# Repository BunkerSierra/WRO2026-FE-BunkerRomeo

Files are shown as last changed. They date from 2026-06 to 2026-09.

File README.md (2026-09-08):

# Equipo Bunker Romeo – WRO Future Engineers 2026

   

## Índice
 
1.  [Acerca del Equipo](#acerca-del-equipo)
2.  [Resumen del Proyecto](#resumen-proyecto)
3.  [1. Movilidad y Diseño Mecánico](#movilidad-mecanico)
   - [Piezas de Diseño Mecánico (CAD)](#piezas-cad)
   - [Fotos del Vehículo (Estado Actual)](#fotos-del-vehiculo)
4.  [2. Arquitectura de Potencia y Sensores](#arquitectura-potencia)
5.  [3. Arquitectura de Software y Estrategia de Obstáculos](#arquitectura-software)
   - [3.1 Open Challenge](#open-challenge-sw)
   - [3.2 Obstacle Challenge](#obstacle-challenge-sw)
     - [1. Marco del reto y objetivos de diseño](#marco-del-reto)
     - [2. Arquitectura general: máquina de estados](#maquina-de-estados)
     - [3. Conjunto de sensores y asignación de funciones](#sensores-obstaculos)
     - [4. Control de rumbo recto](#control-rumbo-recto)
     - [5. Seguimiento de pilares](#seguimiento-pilares)
     - [6. Decisión de sorteo](#decision-sorteo)
     - [7. Detección de esquinas](#deteccion-esquinas)
     - [8. Giro de esquina](#giro-esquina)
     - [9. Auto-ajuste por perfil de servo](#auto-ajuste-servo)
     - [10. Ingeniería defensiva](#ingenieria-defensiva)
     - [11. Odometría y separación de contadores](#odometria)
     - [12. Metodología y decisiones revertidas](#metodologia-decisiones-revertidas)
6.  [4. Pensamiento Sistémico y Decisiones de Ingeniería](#bitacora-decisiones)
7.  [5. Reproducibilidad y Estructura del Repositorio](#reproducibilidad)
8.  [Videos de la Competencia](#videos-de-la-competencia)
   - [Open Challenge](#open-challenge)
   - [Obstacle Challenge](#obstacle-challenge)
9.  [BOM (Bill of Materials)](#bom)
---
 
## Acerca del Equipo

Somos **Equipo Bunker Romeo**, de Bunker Robotics, en Baja California, México. Este es nuestro segundo año participando en la categoría Future Engineers, y comenzamos la preparación de esta temporada en enero de 2025. Entre los dos sumamos experiencia en las categorías Robomission Junior, Robomission Senior y Future Engineers.

<div align="center">
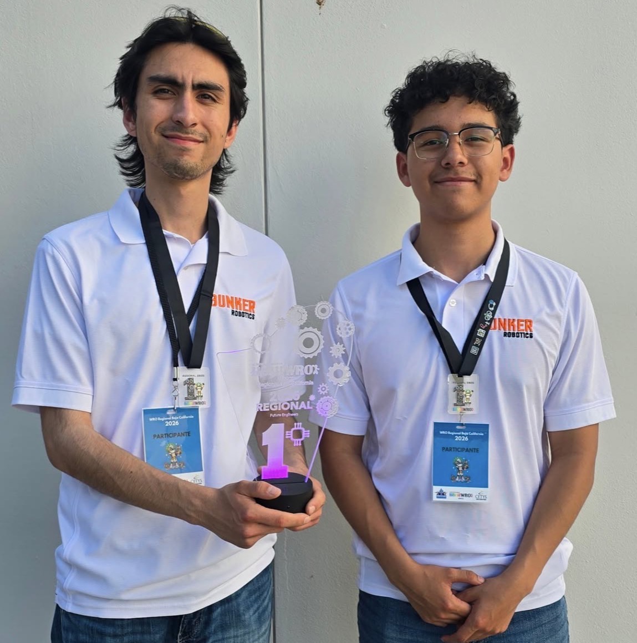
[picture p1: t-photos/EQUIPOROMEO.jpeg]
Equipo Bunker Romeo

</div>

### Jacobo Arteaga Castañeda

**Edad:** 21 años
**Rol:** Operación y desempeño del robot

Compito en WRO desde los 13 años, pasando por las categorías Robomission Junior, Robomission Senior y, desde la temporada 2025, Future Engineers. He tenido la oportunidad de representar a México en la Final Internacional en dos ocasiones: 2021 y 2025. Dentro del equipo soy el responsable de la operación del robot en pista — la puesta a punto antes de cada ronda, el manejo del vehículo durante las corridas de prueba y la lectura del comportamiento real del robot, que es de donde salen la mayoría de los ajustes documentados en la bitácora de este repositorio.

### Ian Fernando Rivera Armenta

**Edad:** 18 años
**Rol:** Documentación y repositorio

Llevo un año en la competencia. Me preparé para Robomission Senior en la temporada 2024 y debuté en Future Engineers, donde en mi primer regional obtuvimos el reconocimiento como mejor equipo. Dentro del equipo soy el responsable del repositorio y de la documentación de ingeniería: mantener el registro de cada decisión de diseño, su justificación y la evidencia que la respalda, además de la organización del código y los archivos técnicos que se publican aquí.

[⬆ Volver al índice](#indicleto)
 
---

## Resumen del Proyecto

Vehículo autónomo desarrollado para la categoría **WRO Future Engineers 2026**, construido sobre un Arduino Mega 2560 con tracción trasera por motor único y dirección por servomotor. El robot resuelve los dos retos con estrategias de navegación distintas: seguimiento de muro por PID en el Open Challenge, y una máquina de estados con visión por color en el Obstacle Challenge.

| | |
|---|---|
| **Dimensiones** | 18.8 × 14.6 × 20.3 cm (largo × ancho × alto) — límite reglamentario: 30 × 20 × 30 cm |
| **Peso** | 817 g — límite reglamentario: 1.5 kg |
| **Tracción** | Motor GA37-520 (300 RPM) con transmisión 1:1 a las ruedas |
| **Percepción** | 2 × VL53L0X (ToF lateral), HC-SR04P (frontal), MPU9250 (rumbo), HuskyLens (color), encoder (odometría) |
| **Mejor tiempo Open Challenge** | **75 s** (3 vueltas + detención en sección de inicio) |
| **Corrida Obstacle Challenge** | **2 min 18 s** completos, autónomos, sin desplazar señales |

**Resultados medidos que respaldan las decisiones de diseño:**

- Reducción del tiempo de Open Challenge de **95 s → 75 s** (≈21 %) al migrar la navegación de rumbo por giroscopio a seguimiento de muro con sensores láser, lo que permitió subir la velocidad del robot sin perder precisión de trayectoria (Decisión 9).
- Corrección de una fuente mecánica de deriva que desviaba la trayectoria recta, eliminando las autocorrecciones constantes del robot en tramo largo (Decisión 13).
- Reducción del footprint del chasis en 2 cm de largo y 2 cm de ancho respecto a la temporada anterior (Decisión 3).
- Altura total reducida de 23.9 cm a **20.3 cm** con el cambio de ruedas (Decisión 3).

[⬆ Volver al índice](#indicleto)
 
---

## 1. Movilidad y Diseño Mecánico

> [!NOTE]
> El razonamiento detrás de cada decisión mecánica —qué alternativas se consideraron y por qué se eligió cada solución— se documenta a detalle en la [Bitácora de Decisiones de Ingeniería](#bitacora-decisiones).

| Aspecto | Especificación actual |
|---|---|
| Ruedas | 57 × 14 mm (Lego Spike Prime) |
| Altura total | 20.3 cm |
| Largo total | 18.8 cm |
| Ancho total | 14.6 cm |
| Peso total | 817 g |
| Controlador principal | Arduino Mega 2560 |

> [!NOTE]
> El chasis fue rediseñado a partir de una versión anterior que usaba ruedas de 62.4 × 20 mm (altura 23.9 cm, ancho 15 cm). Razonamiento completo en la Bitácora, **Decisión 3**.

> [!NOTE]
> Se corrigió un orificio de eje mal dimensionado en el soporte impreso del motor, que causaba una deriva excesiva (~45°) al avanzar en línea recta. La deriva se redujo considerablemente tras el ajuste, aunque persiste en menor grado. Razonamiento completo en la Bitácora, **Decisión 13**.

### Análisis de velocidad y par en rueda

La transmisión entre el motor y las ruedas usa engranes de **1:1** (mismo número de dientes en ambos, por lo que giran a la misma velocidad angular) — es decir, las RPM de la rueda son las mismas que las RPM del motor, sin reducción ni multiplicación.

**Velocidad lineal teórica.** Con el motor **GA37-520** a **300 RPM** (ficha) y ruedas de **57 mm de diámetro**:

```
v = π × D_rueda × RPM / 60
v = π × 0.057 m × 300 / 60
v ≈ 0.895 m/s  (≈ 89.5 cm/s ≈ 3.22 km/h)
```

Esta es la velocidad lineal máxima teórica sin carga; en pista, la velocidad real es menor por la fricción, el peso del robot y el control por PWM.

**Par en la rueda.** El BOM reporta un rango de potencia del motor de **5.55–16.65 W**. A 300 RPM, la velocidad angular es ω = 2π × 300/60 ≈ 31.42 rad/s. Con τ = P/ω:

| | Potencia | Par (τ = P/ω) | Fuerza en el suelo (F = τ / r, r = 28.5 mm) |
|---|---|---|---|
| Mínimo | 5.55 W | ≈ 0.177 N·m (≈ 1.80 kgf·cm) | ≈ 6.2 N (≈ 0.63 kgf) |
| Máximo | 16.65 W | ≈ 0.530 N·m (≈ 5.40 kgf·cm) | ≈ 18.6 N (≈ 1.90 kgf) |

Como la relación de transmisión es 1:1, el par disponible en la rueda es el mismo que el par de salida del motor — no hay ganancia ni pérdida mecánica por relación de engranes, a diferencia de una transmisión reductora.

**Relación con el resultado empírico.** La velocidad teórica de arriba solo se aprovecha si el robot puede correr cerca de ella sin perder el rumbo, y ahí es donde el análisis mecánico se conecta con las decisiones de navegación. Con una transmisión 1:1 no existe una reducción que amortigüe los errores de trayectoria: cada grado de deriva se traduce directamente en distancia recorrida de más y en tiempo perdido autocorrigiendo. Por eso, mientras la navegación dependía del rumbo por giroscopio, la velocidad tenía que mantenerse baja para que el error acumulado no creciera — y el recorrido tomaba **95 segundos**. Al pasar a seguimiento de muro (Bitácora, **Decisión 9**), la referencia dejó de acumular error y pudimos subir la velocidad hasta **75 segundos**. La corrección de deriva mecánica posterior (**Decisión 13**) atacó el mismo problema desde el lado del hardware, permitiendo que esa velocidad se sostuviera en línea recta.

### Piezas de Diseño Mecánico (CAD)

> [!NOTE]
> Todos los archivos `.STL` referenciados aquí están disponibles en la carpeta [`/cad`](cad/) del repositorio. Las dimensiones de cada pieza (caja delimitadora) se obtuvieron directamente del archivo 3D, no son estimaciones.

#### Soporte del sensor láser (VL53L0X)

El soporte impreso en 3D de los sensores láser VL53L0X se rediseñó para elevar al sensor **casi 4 cm por encima** del soporte anterior de MDF. Esta corrección de altura resuelve directamente el hallazgo documentado en la Bitácora (**Decisión 12/13**): el soporte de MDF dejaba al sensor con una leve inclinación hacia el piso, lo que producía falsas lecturas de cercanía (el sensor "veía" el suelo en lugar del muro lateral). Con la nueva geometría, el sensor mide de forma más constante y confiable.

- **Archivo:** [`SoporteLaser.STL`](cad/SoporteLaser.STL)
- **Material:** impreso en 3D (PLA)
- **Dimensiones (caja delimitadora):** 33.9 × 3.1 × 58.6 mm

> [!NOTE]
> Con esta pieza, la falla de montaje que documentamos como "en proceso" en la Bitácora (**Decisión 12**) queda **resuelta** — lo actualizamos en esa entrada.

#### Enlace de dirección y soporte del servomotor

Durante nuestras pruebas encontramos que el barreno de conexión entre el servomotor y el enlace de dirección no estaba centrado: se hallaba desplazado unos milímetros hacia la izquierda. Esto no impedía que el robot funcionara, pero sí desfasaba el ángulo real de las ruedas respecto al ángulo que el servomotor reportaba como centro — es decir, "centro de servo" y "ruedas alineadas" ya no eran el mismo punto. Corregimos la posición del barreno y, aprovechando el rediseño, modificamos también el soporte del servomotor para alojar nuestro nuevo servomotor **ST3215-HS** (ver [Arquitectura de Software](#arquitectura-software) y [Arquitectura de Potencia](#arquitectura-potencia)).
cad/S25_Soporte_Servo_Rev_8.STL
- **Archivo:** [`R26_EnlaceDireccion_Rev7.STL`](cad/R26_EnlaceDireccion_Rev7.STL)[`S25_Soporte_Servo_Rev_8.STL`](cad/S25_Soporte_Servo_Rev_8.STL)
- **Material:** corte en material plano (el enlace en sí no es impreso; el soporte del servomotor que lo acompaña sí es impreso en 3D con PLA)
- **Dimensiones (caja delimitadora):** 116.4 × 3.1 × 17.4 mm

#### Mangueta de dirección

La mangueta es la pieza que se ubica en cada extremo del sistema de dirección y conecta la rueda con el enlace de dirección. Funciona como un pivote: por un lado sostiene el eje/buje de la rueda, y por el otro se articula tanto con el chasis (definiendo el eje de giro de la dirección) como con el enlace de dirección, que es el que recibe el movimiento del servomotor. Cuando el servomotor mueve el enlace de dirección, este empuja o jala la mangueta, haciéndola rotar sobre su propio pivote — y como la rueda está montada directamente en la mangueta, ese giro se traduce en el cambio de ángulo de la rueda. En otras palabras, la mangueta es la que convierte el movimiento lineal/angular del enlace de dirección en el giro real de la rueda.

- **Archivo:** [`S25_Mangueta_Rev_2.STL`](cad/S25_Mangueta_Rev_2.STL)
- **Material:** impreso en 3D (PLA)
- **Dimensiones (caja delimitadora):** 14.4 × 31.9 × 21.0 mm

#### Soporte de motor y transmisión

El eje de salida del motor de tracción está acoplado a ejes Lego, que a su vez conectan directamente con las ruedas. Un soporte personalizado mantiene estos ejes alineados a **180°** entre sí, evitando que se flexionen. Esto es importante por dos razones: evita que se genere una fuerza adicional no deseada sobre el eje Z del motor (que reduciría su vida útil y afectaría la transmisión de potencia), y mantiene un comportamiento consistente y predecible en cada prueba. Esta pieza es de la misma familia que la que corregimos en la Bitácora (**Decisión 13**, orificio de eje mal dimensionado que causaba deriva); esta revisión (**Rev 4B**) es la versión actual, con los ejes correctamente alineados y sin problemas de flexión reportados.

- **Archivo:** [`S25_Soporte_de_motor_y_transmision_Rev_4B.STL`](cad/S25_Soporte_de_motor_y_transmision_Rev_4B.STL)
- **Material:** impreso en 3D (PLA)
- **Dimensiones (caja delimitadora):** 44.5 × 51.8 × 63.5 mm

#### Plataforma / soporte superior

Primer piso del chasis, donde se monta parte de la electrónica del robot.

- **Archivo:** [`R26_piso_1_rev2.STL`](cad/R26_piso_1_rev2.STL)
- **Dimensiones (caja delimitadora):** 114.9 × 3.1 × 26.8 mm

#### Chasis

El chasis se modificó a inicios de esta temporada con el objetivo de reducir el tamaño total del robot y optimizar el acomodo interno de los componentes electrónicos. Como resultado, el chasis actual es **2 cm más corto y 2 cm más angosto** que la versión anterior.

- **Archivo:** [`S25_chasis_rev18.STL`](cad/S25_chasis_rev18.STL)
- **Dimensiones (caja delimitadora):** 177.8 × 3.1 × 135.7 mm

> [!NOTE]
> Material confirmado: la **Mangueta**, el **Soporte de motor y transmisión**, el **Soporte del sensor láser** y el **soporte del servomotor** (parte de la pieza "Enlace de dirección y soporte del servomotor") son impresos en 3D con **PLA**. El **Enlace de dirección** (la barra en sí) es de corte en material plano, no PLA. El **Chasis** y la **Plataforma/Soporte** tienen un espesor uniforme de 3.1 mm en el archivo, consistente con corte en material plano (MDF/acrílico).

### Fotos del Vehículo (Estado Actual)

<table align="center">
<tr>
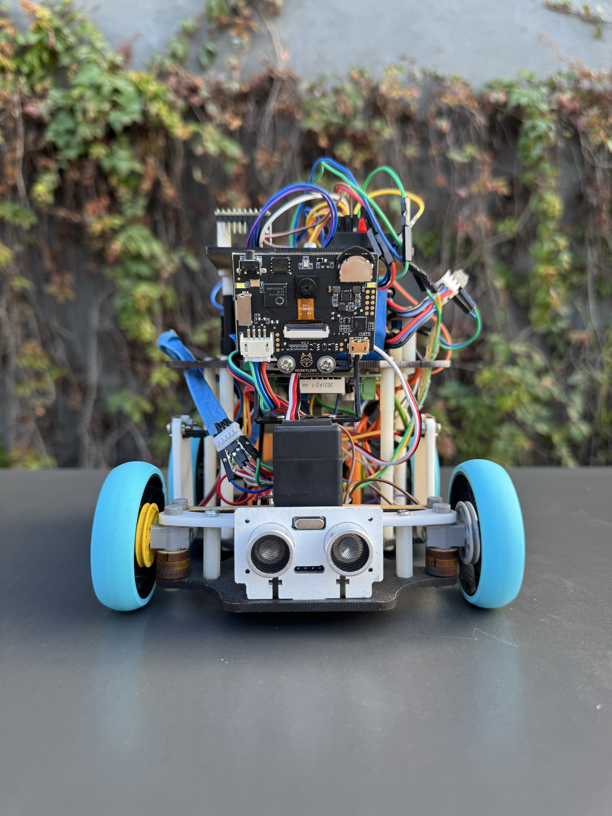
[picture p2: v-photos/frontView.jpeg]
<td align="center"><br><sub>Vista Frontal</sub></td>
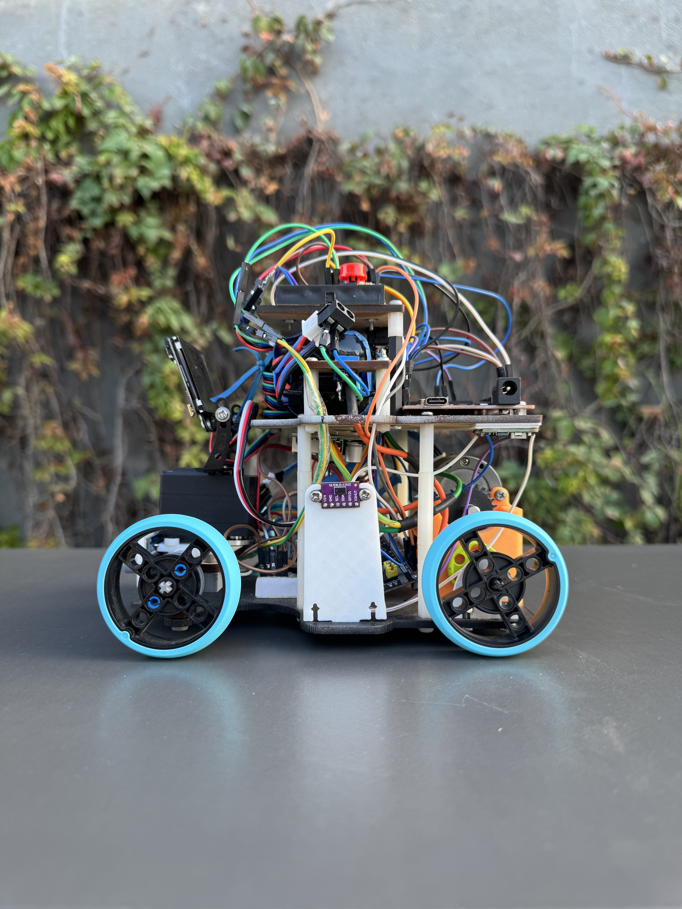
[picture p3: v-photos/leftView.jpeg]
<td align="center"><br><sub>Vista Lateral Izquierda</sub></td>
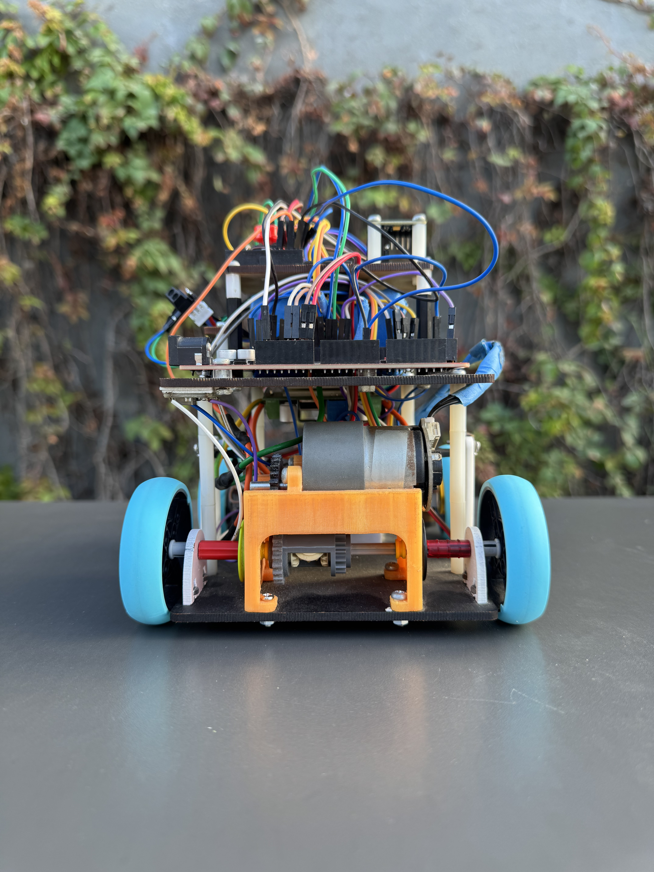
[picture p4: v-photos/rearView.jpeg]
<td align="center"><br><sub>Vista Trasera</sub></td>
</tr>
<tr>
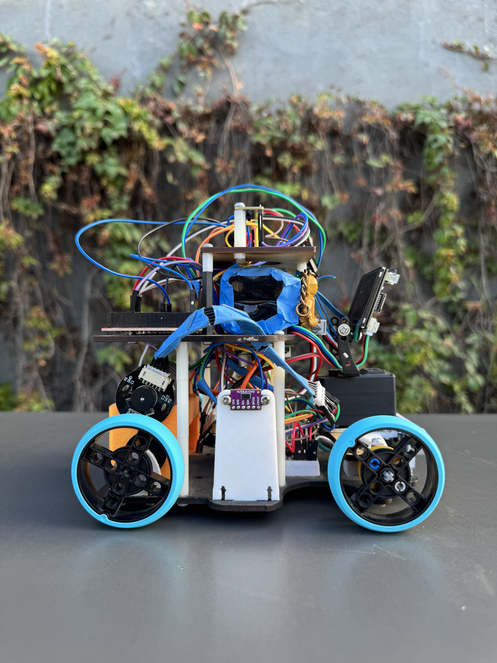
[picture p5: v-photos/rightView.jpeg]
<td align="center"><br><sub>Vista Lateral Derecha</sub></td>
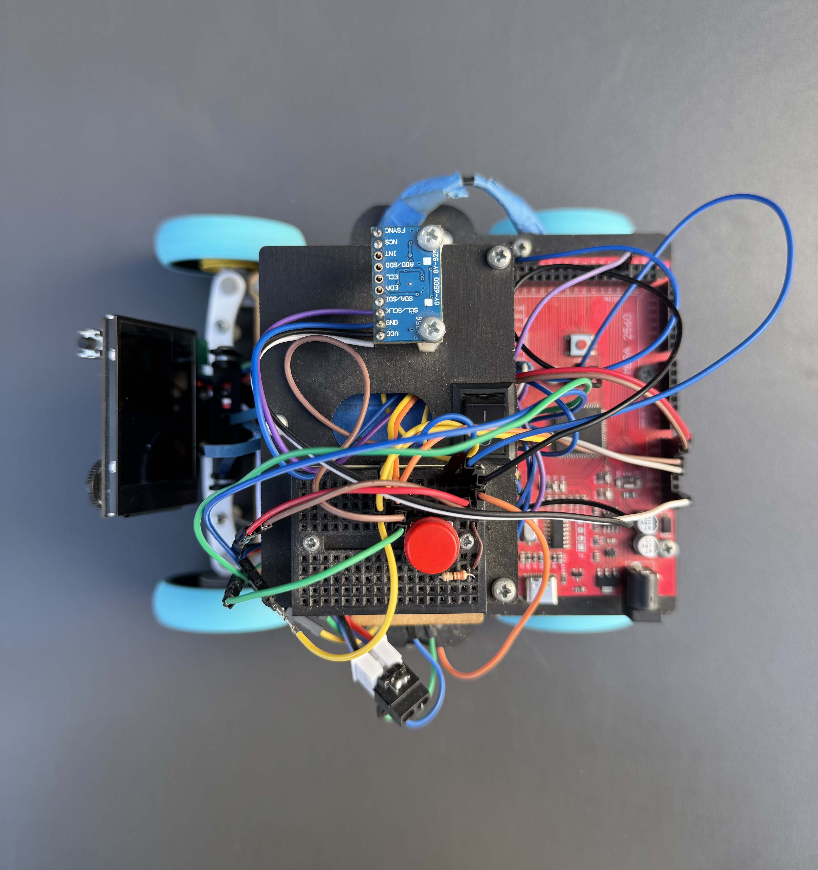
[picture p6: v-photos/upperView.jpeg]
<td align="center"><br><sub>Vista Superior</sub></td>
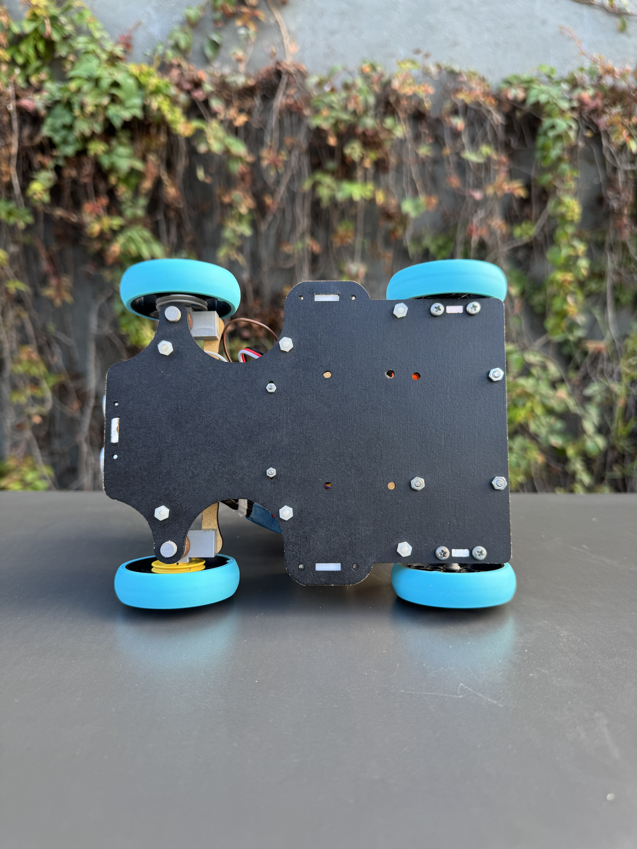
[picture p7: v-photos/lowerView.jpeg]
<td align="center"><br><sub>Vista Inferior</sub></td>
</tr>
</table>

[⬆ Volver al índice](#indicleto)
 
---

## 2. Arquitectura de Potencia y Sensores

> [!NOTE]
> Esta sección detalla cómo se reparte la energía dentro del robot —de la batería a cada sensor y actuador— y el presupuesto de corriente que resulta de esa distribución.

### Topología de alimentación

El robot se alimenta de una sola batería de **15 V**, que pasa primero por un **switch** general y de ahí se reparte entre **dos ramas de regulación step-down**: una hacia control y tracción, y otra dedicada en exclusiva a la dirección.

- **Regulador a 11.1 V:** su salida alimenta directamente al **motor de tracción** (a través del puente H TB6612FNG) y al **Arduino Mega** por su entrada Vin. De los **5 V** que el propio Arduino regula internamente se alimentan los sensores: los **dos sensores láser** (VL53L0X), el **girosensor** (MPU9250/GY-9250), la **cámara** (HuskyLens) y el **sensor ultrasónico** (HC-SR04P).
- **Regulador a 6 V:** alimenta, en línea dedicada, al **servomotor del Open Challenge (MG90S)**.
- **Regulador a 7.5 V:** alimenta, también en línea dedicada, al **servomotor del Obstacle Challenge (Waveshare ST3215-HS)**.

Ambos servos tienen su propia línea de alimentación exclusiva (no comparten regulador con ningún otro componente) porque consideramos que el servomotor es la variable principal de posicionamiento para resolver los retos: si no tiene la corriente disponible en el momento exacto, toda la precisión de dirección se ve comprometida.

<div align="center">
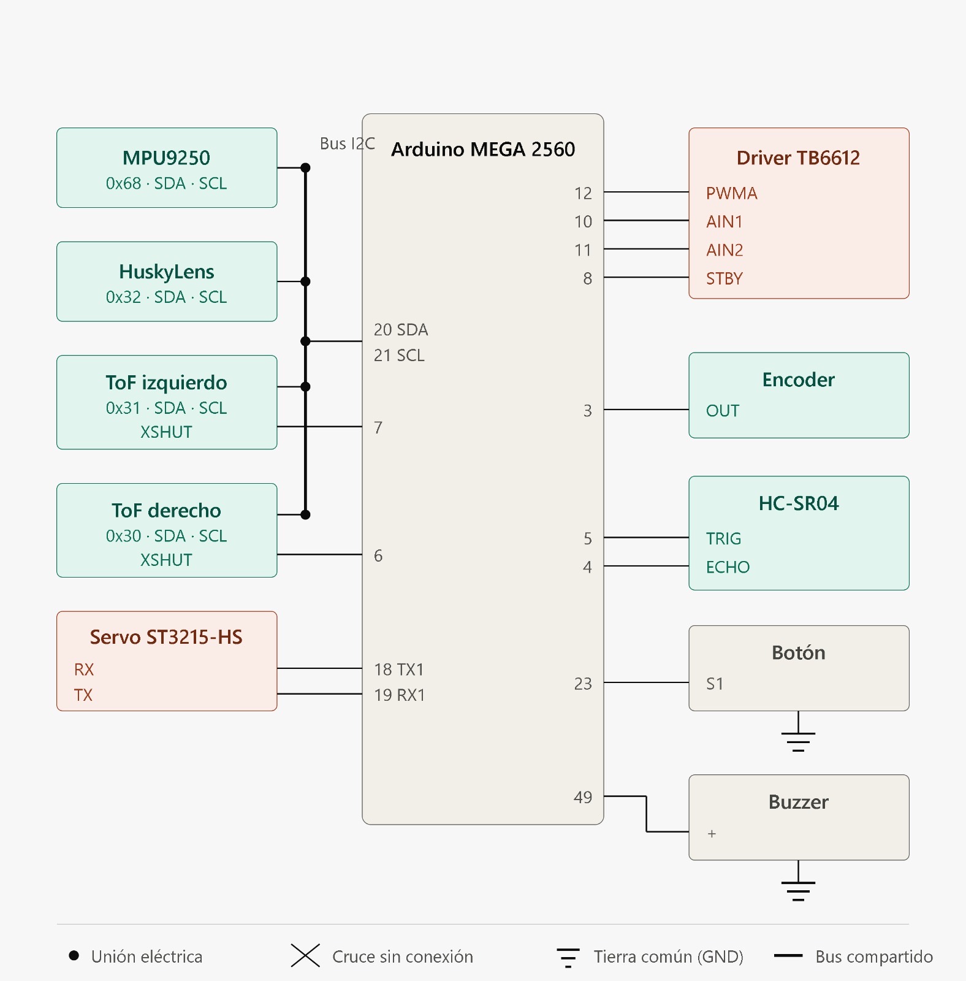
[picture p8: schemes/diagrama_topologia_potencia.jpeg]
Diagrama de topología de alimentación

<br><sub>Topología de alimentación: batería → switch → tres ramas de regulación (11.1 V control/tracción, 6 V servo Open Challenge, 7.5 V servo Obstacle Challenge).</sub>
</div>

```
Batería 15 V → Switch ─┬─ Regulador 11.1 V ─┬─ Motor de tracción (vía TB6612FNG)
                        │                    └─ Arduino Mega → (5 V) → VL53L0X ×2, GY-9250, HuskyLens, HC-SR04P
                        ├─ Regulador 6 V   ──── Servomotor MG90S (Open Challenge, línea dedicada)
                        └─ Regulador 7.5 V ──── Servo ST3215-HS (Obstacle Challenge, línea dedicada)
```

### Diagrama de conexiones (pines)

<div align="center">
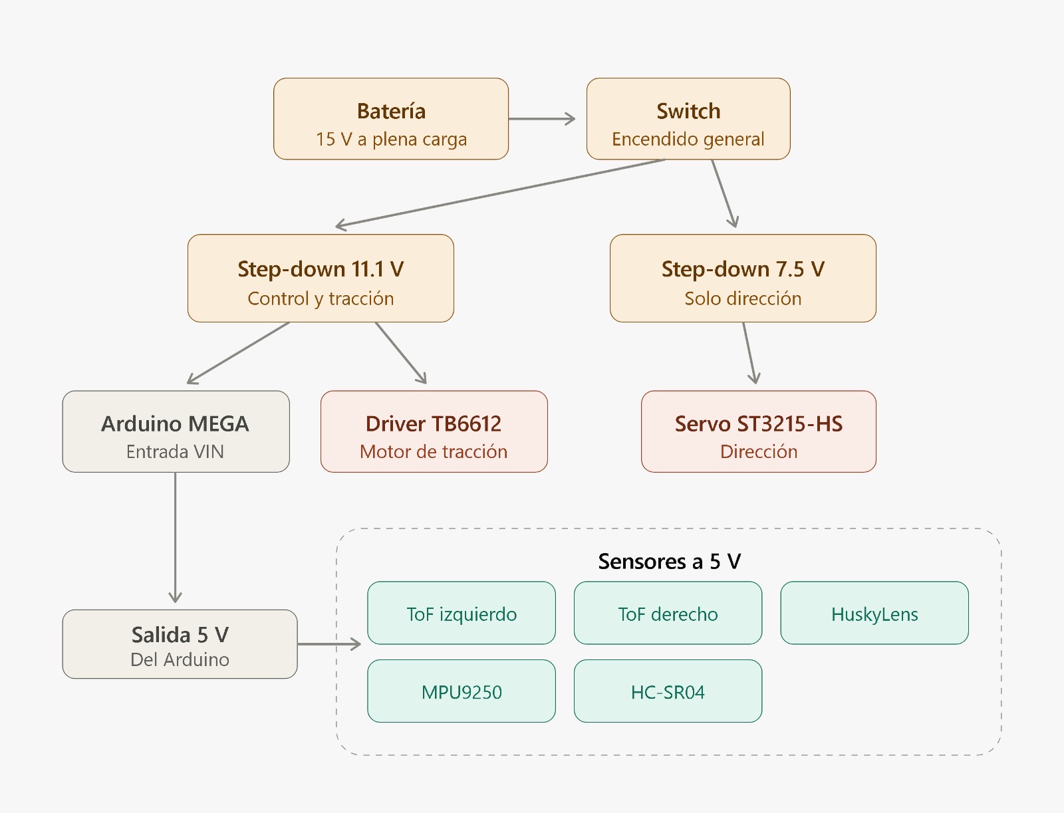
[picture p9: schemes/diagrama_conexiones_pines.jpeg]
Diagrama de conexiones y pines del Arduino Mega

<br><sub>Conexión de cada componente a los pines del Arduino Mega 2560: PWMA/AIN1/AIN2/STBY (12, 10, 11, 8) al driver TB6612; XSHUT (7, 6) y bus I2C (20 SDA, 21 SCL) para los VL53L0X, MPU9250 y HuskyLens; encoder en el pin 3; HC-SR04P en TRIG/ECHO (5, 4); Serial1 (18 TX1, 19 RX1) para el servo ST3215-HS; botón en el pin 23; buzzer en el pin 49.</sub>
</div>

### Presupuesto de corriente

| Componente | Imagen | Voltaje de uso | Consumo de corriente |
|---|---|---|---|
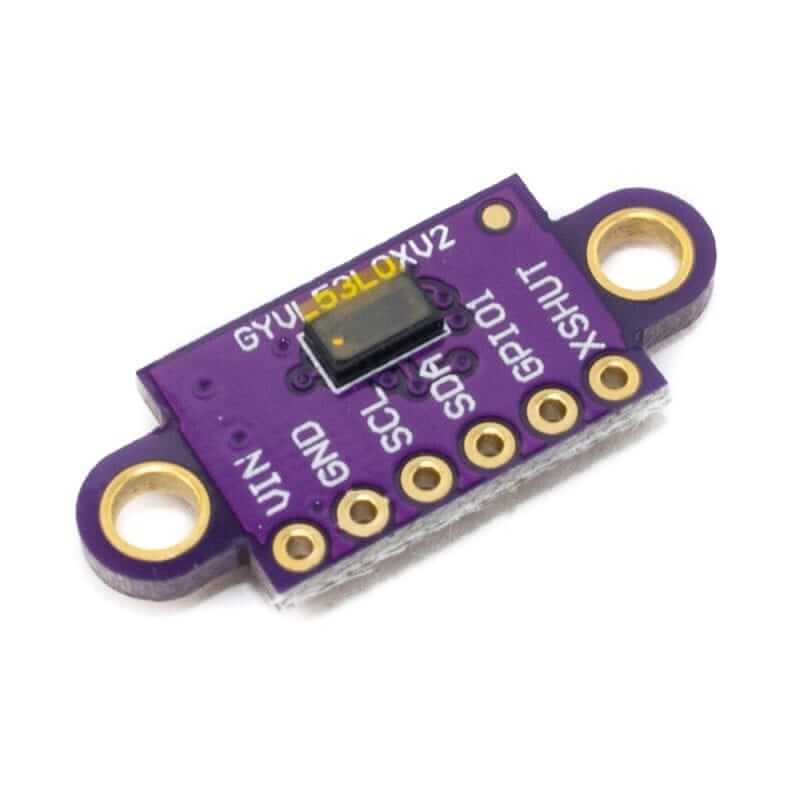
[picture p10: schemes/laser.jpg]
| Sensor láser VL53L0X |  | 5 V | ≈ 10 mA (x2) |
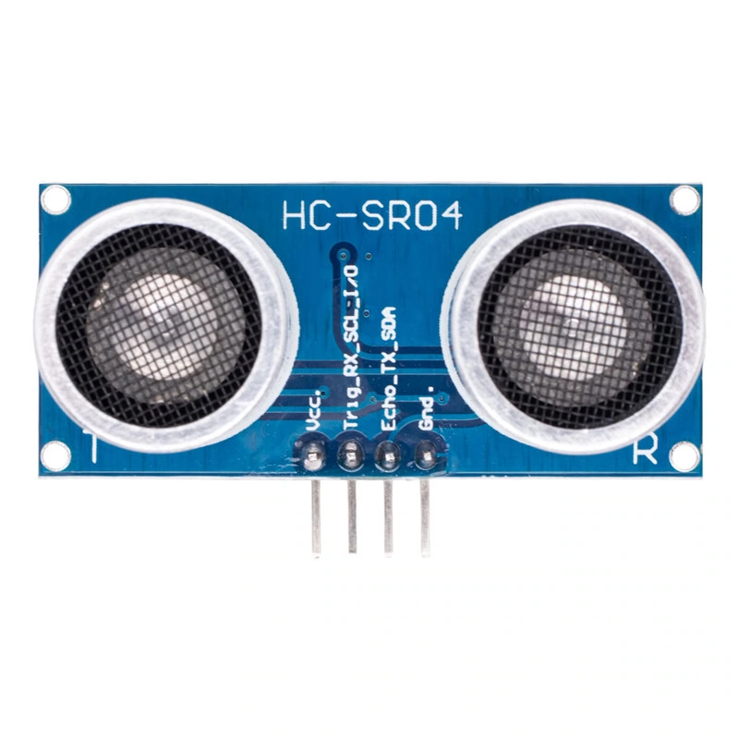
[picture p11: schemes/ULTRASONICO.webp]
| Sensor ultrasónico HC-SR04P |  | 5 V | ≈ 15 mA |
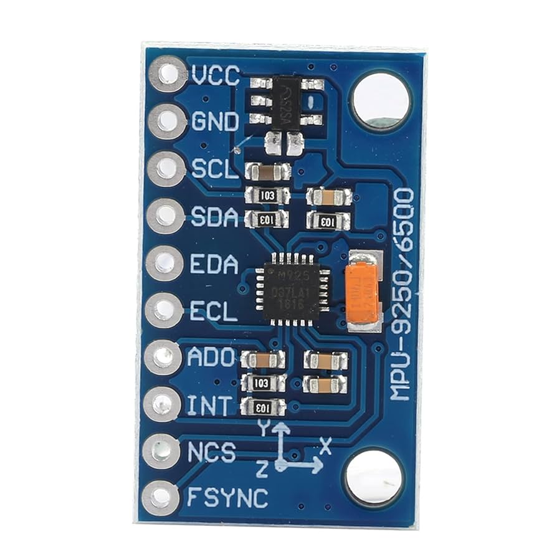
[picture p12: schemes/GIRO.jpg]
| Girosensor GY-9250 |  | 5 V | ≈ 6.6 mA |
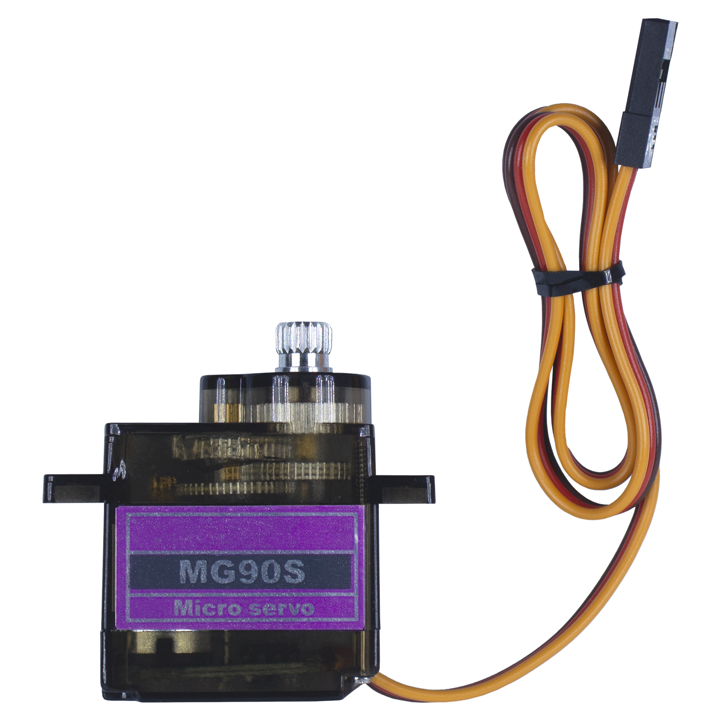
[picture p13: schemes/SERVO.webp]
| Servomotor MG90S (Open Challenge) |  | 6 V | ≈ 83–417 mA |
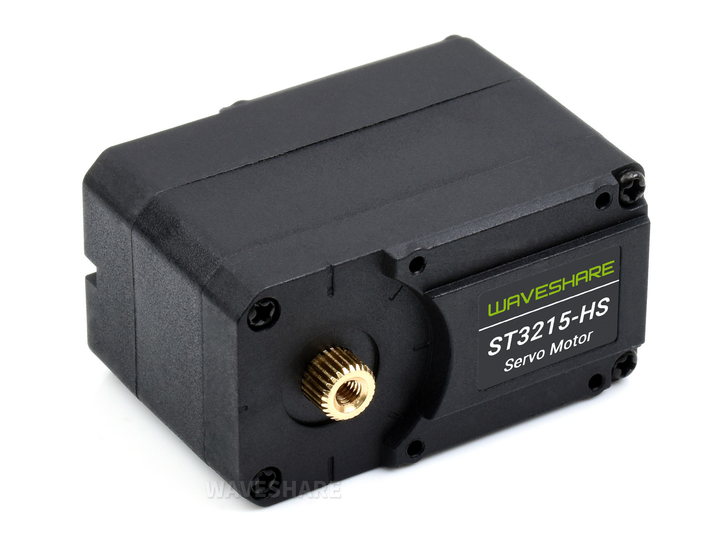
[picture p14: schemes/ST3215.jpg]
| Servo ST3215-HS (Obstacle Challenge) |  | 7.5 V | ≈ 100–900 mA |
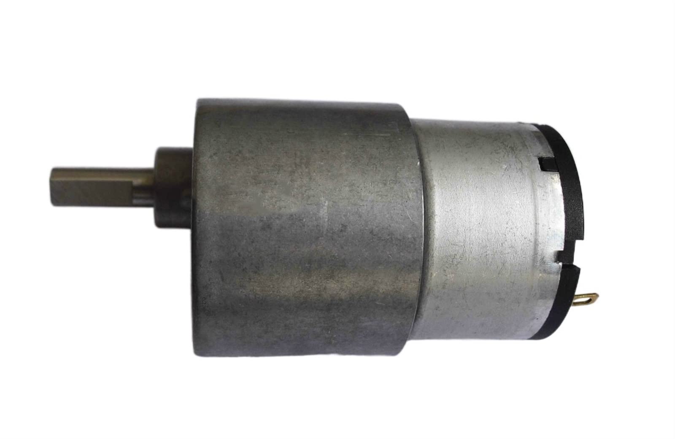
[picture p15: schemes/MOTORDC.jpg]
| Motor de tracción GA37-520 |  | 11.1 V | ≈ 500–1500 mA |
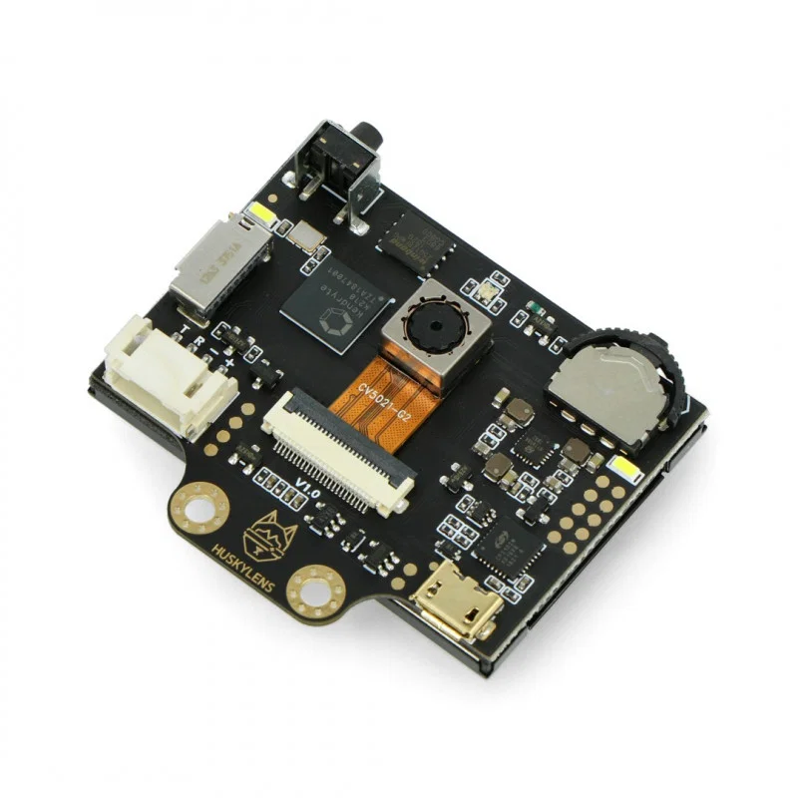
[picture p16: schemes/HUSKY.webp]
| Cámara HuskyLens |  | 5 V | ≈ 320 mA |
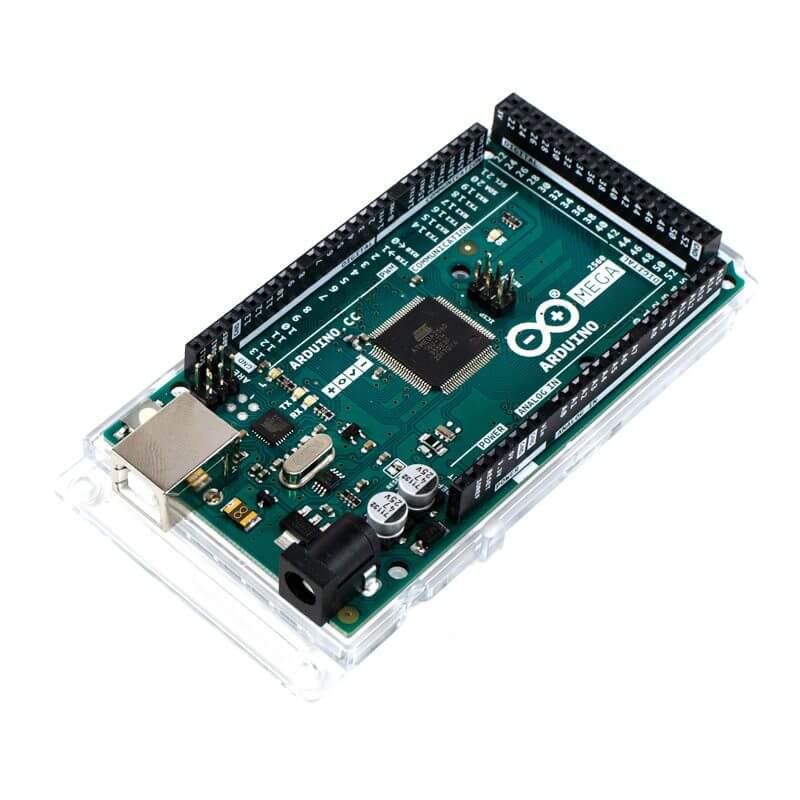
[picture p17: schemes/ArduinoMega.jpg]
| Arduino Mega 2560 |  | 11.1 V | ≈ 22.5–45 mA |
| **Total (Open Challenge)** | | | **≈ 967 mA – 2.32 A** |
| **Total (Obstacle Challenge)** | | | **≈ 984 mA – 2.80 A** |

> [!NOTE]
> Cada consumo se obtuvo de la ficha técnica del componente, referido al voltaje real al que opera en este circuito. Los totales suman corriente de rieles distintos (5 V, 6 V/7.5 V y 11.1 V) según el reto; la corriente que efectivamente entrega la batería es menor y depende de la eficiencia de cada regulador step-down.

[⬆ Volver al índice](#indicleto)
 
---

## 3. Arquitectura de Software y Estrategia de Obstáculos

> [!NOTE]
> Esta sección cuenta, en nuestras propias palabras, **cómo y por qué** funciona el software del robot en cada reto: la arquitectura de control, qué sensor hace qué, el código real que corre en el Arduino, y el razonamiento (y los tropiezos) detrás de cada subsistema. Complementa a la [Bitácora de Decisiones de Ingeniería](#bitacora-decisiones), que lleva la línea de tiempo de los cambios de hardware/algoritmo a nivel de proyecto.

### 3.1 Open Challenge

En el Open Challenge no hay pilares que sortear, así que el problema se reduce a completar 3 vueltas (12 esquinas en total) manteniendo una distancia constante a un muro y girando con precisión en cada esquina. Por eso este programa es más simple que el del Obstacle Challenge: no usa cámara de color, y el servo de dirección es un **MG90S** estándar controlado con la librería `Servo` de Arduino (a diferencia del servo de bus serial que usamos en el Obstacle Challenge).

**Hardware que usa este programa:** servomotor MG90S (dirección), sensor ultrasónico HC-SR04P (frontal), dos VL53L0X laterales (seguimiento de muro), giroscopio MPU6050 vía librería `MPU6050_light` (rumbo y giros), encoder (tramo final), y el puente H TB6612FNG (motor de tracción).

**Detección de esquina y sentido de giro.** El robot avanza hasta que el ultrasónico frontal detecta una pared a **30 cm o menos** (`TD = 30`). En la primerísima esquina de toda la ronda, y solo ahí, compara las dos lecturas laterales VL53L0X (`decideSentido()`): el lado que ve más lejos es el interior de la pista, y ese es el sentido de giro que se usa durante **las 12 esquinas** de la ronda, sin volver a recalcularlo.

**Tramo recto.** Antes de la primera esquina el robot todavía no tiene un muro "conocido" que seguir, así que avanza en línea recta usando el giroscopio (`conduceRectoGiro()`: un control proporcional que corrige el volante para mantener el rumbo en 0°). De la segunda esquina en adelante, cada tramo recto se recorre con **seguimiento de muro por PID** (`Kp=17, Ki=0.5, Kd=35`, punto de ajuste de **15 cm**, función `Wallfolowing()`), siempre sobre el lado **exterior** de la pista — el sensor contrario al lado de giro — porque el muro exterior es continuo, mientras que el interior tiene aberturas en cada esquina.

> [!NOTE]
> **Método de calibración de las ganancias PID:** las tres ganancias se ajustaron de forma empírica y en este orden: primero **Kp**, subiéndola hasta que el robot oscilara visiblemente contra el muro y luego bajándola un escalón; después **Kd**, para amortiguar esa oscilación sin perder capacidad de reacción; y por último **Ki**, en un valor bajo, solo para corregir el desvío sostenido que quedaba en tramos largos. El punto de ajuste de 15 cm se eligió porque deja margen suficiente tanto en el corredor angosto (600 mm) como en el ancho (1000 mm) que define el reglamento para el Open Challenge, sin acercar demasiado al robot al muro interior en el corredor angosto.

**Maniobra de giro.** Al detectar la pared frontal, el robot cierra el giro en lazo con el giroscopio hasta alcanzar un ángulo objetivo (`Giros()`). Estos ángulos se calibraron de forma empírica y son acumulativos dentro de cada vuelta (se reinician cada 4 esquinas): **60°** en la 1ª esquina de la vuelta, **120°** en la 2ª, **182°** en la 3ª y **241°** en la 4ª. Al terminar, el robot reduce su velocidad y continua siguiendo la pared hasta contar cierta cantidad de pulsos con el encoder, y el robot se detiene.

**Cierre de la ronda.** Tras completar las 12 esquinas, el robot reduce la velocidad y continúa con seguimiento de muro por una distancia fija adicional (2555 pulsos de encoder) antes de detenerse — este tramo final lo acerca a la zona de estacionamiento.

<details>
<summary>📄 Ver código completo — Open Challenge (<code>abierto.ino</code>)</summary>

```cpp
#include <Adafruit_VL53L0X.h>  // ToF sensor Library
#include <Servo.h>             // Servomotor Library
#include <Wire.h>              // I2C Library
#include <MPU6050_light.h>     // MPU Library
MPU6050 mpu(Wire);

// Variables para el yaw
float yaw = 0.0;
unsigned long lastTime = 0;
float gyroZOffset = 0.0;

// Para calibración
bool calibrated = false;
const int CALIBRATION_SAMPLES = 510;

volatile int Contador = 0;

unsigned long Cont = 0;
bool izq = false;

float global = 0;

//PID Wall Follower variables
float P, I, D, error, L_error, Servo_OUT, DeltaError, SumError, PID;
float setpoint = 15;  //Centimetros
float Kp = 17, Ki = 0.5, Kd = 35;
float Ts = 0.5;  // Tiempo de sampleo para la suma de la integral

//Trasnmision Motor
const int STBY = 8;
const int PWMA = 12;
const int AIN1 = 10;
const int AIN2 = 11;

//Servo Direccion
Servo SvD;

//Ultrasonic Frontal Sensor
const int triggerPin3 = 5;
const int echoPin3 = 4;
volatile float distanceF;

//ToF Lateral Sensors
#define XSHUT1 6
#define XSHUT2 7
Adafruit_VL53L0X sensor1 = Adafruit_VL53L0X();
Adafruit_VL53L0X sensor2 = Adafruit_VL53L0X();
float medidaD, medidaI;

//Algorithim Variables/Values
float TD = 30;  //Target frontal distance ... CM
bool Turn = true;
bool Orientation = false;
bool Giro = false;
int CV;

int sentidoGiro = 2;     // se decide solo en el 1er corner: 1=derecha, 2=izquierda
float Kp_rumbo = 3.0;    // ganancia del rumbo recto por giroscopio (1er tramo)

void setup() {
  Serial.begin(115200);
  Wire.begin();

  pinMode(3, INPUT_PULLUP);
  attachInterrupt(digitalPinToInterrupt(3), inter, RISING);

  pinMode(triggerPin3, OUTPUT);
  pinMode(echoPin3, INPUT);

  Wire.beginTransmission(0x68);
  Wire.write(0x6B);
  Wire.write(0);
  Wire.endTransmission(true);

  pinMode(STBY, OUTPUT);
  pinMode(PWMA, OUTPUT);
  pinMode(AIN1, OUTPUT);
  pinMode(AIN2, OUTPUT);
  // The motor begins off
  digitalWrite(STBY, LOW);

  pinMode(XSHUT1, OUTPUT);
  pinMode(XSHUT2, OUTPUT);

  SvD.attach(A1);
  delay(50);
  tone(49, 293, 125);
  delay(50);

  SvD.write(105);
  delay(400);

  byte status = mpu.begin();
  while (status != 0) {}

  mpu.calcOffsets();  // Calibración interna de la librería
  calibrateGyroZ();   // Calibración adicional específica para Z

  lastTime = millis();
  calibrated = true;

  tone(49, 1000, 125);

  // Apagar los tres sensores
  digitalWrite(XSHUT1, LOW);
  digitalWrite(XSHUT2, LOW);
  delay(10);

  // Encender sensor 1 y darle dirección 0x30
  digitalWrite(XSHUT1, HIGH);
  delay(10);
  sensor1.begin(0x30);

  // Encender sensor 2 y darle dirección 0x31
  digitalWrite(XSHUT2, HIGH);
  delay(10);
  sensor2.begin(0x31);
  
}

void loop() {

  while (CV < 12) {
    distanceF = TD + 3;
    SUSF();
    delay(20);

    if (distanceF <= TD) {
      if (CV == 0) decideSentido();     // 1er corner: decide el sentido de TODAS las vueltas
      Giros(sentidoGiro, 175, 60);
      tone(49, 290, 75);
      distanceF = TD + 100;
      CV++;
      delay(1);
      if (CV == 4 || CV == 8 || CV == 12) {
        global = 0;
        yaw = 0;
      }
      SvD.write(105);
    } else {
      if (CV == 0) {
        conduceRectoGiro();             // antes del 1er corner: avanza recto por giroscopio (sin seguir pared)
        moverMotor(200);
      } else {
        Wallfolowing();
        moverMotor(200);
      }
    }
  }
  if (CV >= 12) {
    moverMotor(120);
    while (Contador < (Cont + 2555)) {
      Wallfolowing();;
    }
    detenerMotores(1000000000000000000000000000000000000000000000000000);
  }
}

// ===== Decide el sentido de giro en el 1er corner: lee ambos ToF, gira al lado mas abierto =====
void decideSentido() {
  VL53L0X_RangingMeasurementData_t m1, m2;
  sensor1.rangingTest(&m1, false);
  sensor2.rangingTest(&m2, false);
  float izq = m1.RangeMilliMeter / 10.0;   // sensor1 = lado IZQUIERDO (medidaI)
  float der = m2.RangeMilliMeter / 10.0;   // sensor2 = lado DERECHO  (medidaD)
  Serial.print("izq="); Serial.print(izq);
  Serial.print("  der="); Serial.println(der);
  // El lado que mide MAS es el mas abierto -> se gira hacia ese lado.
  // Si decide al reves en tu robot, invierte esta comparacion (cambia > por <).
  if (izq > der) {
    Orientation = false; sentidoGiro = 2;              // abierto IZQUIERDA -> gira izquierda
    tone(49, 1200, 120); delay(160); tone(49, 1200, 120);
  } else {
    Orientation = true;  sentidoGiro = 1;              // abierto DERECHA -> gira derecha
    tone(49, 700, 250);
  }
  delay(150);
}

// ===== Avance recto por giroscopio (rumbo objetivo = 0), sin seguir pared =====
void conduceRectoGiro() {
  GradoZ();                                // actualiza yaw
  float err = 0 - yaw;                      // mantiene el rumbo inicial (yaw = 0)
  int salida = 105 + (int)(Kp_rumbo * err);
  salida = constrain(salida, 35, 160);
  SvD.write(salida);
}

void SUSF() {
  digitalWrite(triggerPin3, LOW);
  delayMicroseconds(2);
  digitalWrite(triggerPin3, HIGH);
  delayMicroseconds(10);
  digitalWrite(triggerPin3, LOW);
  long durationF = pulseIn(echoPin3, HIGH);
  distanceF = durationF / 58;
}
void Wallfolowing() {
  //Obtencion del dato del sensor.
  if (Orientation == true) {
    VL53L0X_RangingMeasurementData_t medida1;
    sensor1.rangingTest(&medida1, false);
    delay(5);
    medidaI = medida1.RangeMilliMeter / 10;
    error = medidaI - setpoint;
  } else {
    VL53L0X_RangingMeasurementData_t medida2;
    sensor2.rangingTest(&medida2, false);
    delay(5);
    medidaD = medida2.RangeMilliMeter / 10;
    error = medidaD - setpoint;
  }
  DeltaError = error - L_error;
  SumError += L_error;
  P = Kp * error;
  I = Ki * Ts * SumError;
  I = constrain(I, -55, 55);
  D = ((Kd / Ts) * DeltaError);
  PID = P + I + D;
  L_error = error;

  PID = constrain(PID, -10, 10);
  if (Orientation == true) {
    Servo_OUT = 105 - PID;
  } else {
    Servo_OUT = 105 + PID;
  }
  SvD.write(Servo_OUT);
}
void moverMotor(int velocidad) {
  digitalWrite(STBY, HIGH);
  if (velocidad > 0) {
    digitalWrite(AIN1, HIGH);
    digitalWrite(AIN2, LOW);
  } else {
    digitalWrite(AIN1, LOW);
    digitalWrite(AIN2, HIGH);
    velocidad = -velocidad;
  }
  analogWrite(PWMA, constrain(velocidad, 0, 255));
}

void inter() {
  Contador++;
}

void MotorEnc(int velocidad, int pulsos) {
  Contador = 0;
  delay(5);

  digitalWrite(STBY, HIGH);
  if (velocidad > 0) {
    digitalWrite(AIN1, HIGH);
    digitalWrite(AIN2, LOW);
    analogWrite(PWMA, constrain(velocidad, 0, 255));
    while (Contador <= pulsos) {}

  } else {
    digitalWrite(AIN1, LOW);
    digitalWrite(AIN2, HIGH);
    analogWrite(PWMA, constrain(-velocidad, 0, 255));
    while (Contador <= pulsos) {}
  }

  detenerMotores(0);
}

void detenerMotores(int T) {
  analogWrite(PWMA, 0);
  digitalWrite(STBY, LOW);  // Standby to save energy
  delay(T);
}

void calibrateGyroZ() {
  float sum = 0;
  for (int i = 0; i < CALIBRATION_SAMPLES; i++) {
    mpu.update();
    sum += mpu.getGyroZ();
    delay(5);
  }
  gyroZOffset = sum / CALIBRATION_SAMPLES;
  Serial.print("Gyro Z Offset: ");
  Serial.println(gyroZOffset, 6);
}

void GradoZ() {
  mpu.update();

  if (calibrated) {
    unsigned long currentTime = millis();
    float deltaTime = (currentTime - lastTime) / 1000.0;  // Tiempo en segundos
    lastTime = currentTime;

    if (deltaTime > 0.1) deltaTime = 0.01;  // Limitar deltaTime máximo

    // Obtener velocidad angular Z (grados/segundo) y aplicar offset
    float gyroZRate = mpu.getGyroZ() - gyroZOffset;

    // INTEGRAR para obtener el ángulo: ángulo = velocidad angular × tiempo
    yaw += gyroZRate * deltaTime;

    // Mantener el yaw en el rango 0-360 grados
    if (yaw <= -360) yaw = 0;
    if (yaw >= 360) yaw = 0;
    Serial.println(yaw);
  }

  delay(12);  // Little Pause for estability
}

void Giros(int d, int V, float G) {
  tone(49, 3520, 50);
  GradoZ();
  float targetYaw;
  if (d == 1) SvD.write(160);
  else { SvD.write(35); }

  delay(50);

  if (CV == 0 || CV == 4 || CV == 8) targetYaw = G;
  else if (CV == 1 || CV == 5 || CV == 9) targetYaw = G * 2;
  else if (CV == 2 || CV == 6 || CV == 10) targetYaw = (G * 3) + 2;
  else if (CV == 3 || CV == 7 || CV == 11) targetYaw = (G * 4) + 1;
  if (d != 1) targetYaw = targetYaw * -1;

  global = targetYaw;

  moverMotor(V);

  while (true) {
    GradoZ();

    if (d == 1) {
      if (yaw >= targetYaw) {
        break;
      }
    } else {
      if (yaw <= targetYaw) {
        break;
      }
    }
  }

  MotorEnc(-115, 13);
  delay(100);

  if (d == 1) dir(160, 105, 10);
  else { dir(35, 105, 10); }

  SvD.write(105);
  delay(50);
  SvD.write(105);
}

void dir(int Vi, int Vf, int T) {
  if (Vi < Vf) {
    for (int pos = Vf; pos <= Vi; pos += 5) {
      SvD.write(pos);
      delay(T);
    }
  } else {
    for (int pos = Vf; pos >= Vi; pos -= 5) {
      SvD.write(pos);
      delay(T);
    }
  }
  SvD.write(105);
}
```

</details>

[⬆ Volver al índice](#indicleto)

---

### 3.2 Obstacle Challenge

#### 1. Marco del reto y objetivos de diseño

El Obstacle Challenge de WRO Future Engineers 2026 le pide al vehículo recorrer, de forma completamente autónoma, tres vueltas a una pista de ocho secciones —cuatro esquinas y cuatro rectas— mientras esquiva señales de tráfico colocadas al azar antes de cada ronda. La regla es simple de decir pero exigente de cumplir: un pilar **rojo** obliga a pasar por su lado **derecho**, uno **verde** por el **izquierdo**, y en ningún caso se puede mover la señal. Como el sentido de la ronda (horario o antihorario) se decide al azar justo antes de arrancar, el algoritmo no puede asumir nada de entrada: tiene que averiguarlo por sí mismo apenas empieza a moverse. Y al final, después de las tres vueltas, hay que volver al estacionamiento.

Desde el principio nos propusimos tres cosas al diseñar el sistema: que aguantara bien la aleatoriedad (posición de pilares, sentido de la ronda), que dependiera lo menos posible de la iluminación o de medidas exactas de la pista, y que se pudiera depurar por partes. Esta última terminó siendo casi la regla de oro del equipo: **medir antes de prescribir**. Cada valor que importaba lo dejamos como una constante ajustable, y cada subsistema lo probamos aislado en su propio programa antes de juntarlo con los demás — así, cuando algo fallaba, sabíamos exactamente en qué módulo buscar.

#### 2. Arquitectura general: máquina de estados

El control del robot está organizado como una **máquina de estados** que, básicamente, calca la forma de la pista. En cada tramo recto, el vehículo pasa por cuatro estados:

- **RECTO:** avanza manteniendo el rumbo.
- **SEGUIR:** al detectar un pilar, lo centra en el cuadro de la cámara mientras se acerca.
- **ESQUIVAR:** al llegar a cierta distancia, ejecuta la maniobra de esquive.
- **REGRESAR:** retoma el rumbo recto.

Por encima de todo esto, el robot también puede entrar en la maniobra de esquina — pero solo si está en estado RECTO. Esa restricción fue una decisión a propósito: así nos aseguramos de que el robot nunca intente doblar una esquina a la mitad de un esquive, resolviendo de una vez el conflicto entre "sortear el pilar" y "tomar la esquina" a favor de lo primero.

Separar el control de esta manera nos permitió que cada tarea usara el sensor que mejor le quedaba, sin que se estorbaran entre sí: la cámara maneja SEGUIR y ESQUIVAR, el giroscopio se encarga del rumbo en RECTO y REGRESAR (y del giro de esquina), los sensores de distancia detectan las esquinas, y el encoder le da la odometría a todas las maniobras.

#### 3. Conjunto de sensores y asignación de funciones

Sobre un Arduino Mega, el robot integra cinco sistemas de percepción/actuación, la mayoría conectados por el mismo bus I2C:

- **Cámara HuskyLens** (modo de reconocimiento de color): detecta los pilares y da su posición horizontal en el cuadro, además de su alto aparente en píxeles, que usamos como estimador de qué tan cerca está el pilar (no usamos un sensor de distancia dedicado para los pilares).
- **Dos sensores de tiempo de vuelo VL53L0X**, en **modo de largo alcance**: detectan cuándo se abre una esquina y, si hace falta, sirven para decidir si conviene un giro hacia adelante o en reversa. La altura de montaje no es arbitraria: el soporte rediseñado (ver [Piezas de Diseño Mecánico](#piezas-cad)) eleva al sensor casi 4 cm respecto al soporte anterior, lo que lo deja apuntando dentro de la franja de los **100 mm de altura** que especifica el reglamento para los muros de la pista (regla 13.3/13.5) — ni tan bajo que lea el piso, ni tan alto que pase por encima del muro.
- **Giroscopio (GY-9250, vía MPU6050):** calcula el rumbo (*yaw*) integrando la velocidad angular — es la base tanto del control en línea recta como de los giros.
- **Encoder** de un canal en el eje de tracción: da la distancia recorrida para todas las maniobras basadas en odometría.
- **Servomotor de dirección Waveshare ST3215:** a diferencia del Open Challenge (que usa un MG90S estándar), aquí usamos un servo de **bus serial** (protocolo half-duplex por `Serial1`, librería `SCServo`), que permite fijar posición, velocidad y aceleración de forma independiente. Esto nos deja calcular cuánto tarda el volante en llegar a cada ángulo y **compensar ese retraso** al calcular las distancias de esquive, giro y frenado (ver punto 9, más abajo) — algo que un servo PWM normal no nos permitiría hacer con la misma precisión.

Repartir las tareas entre sensores especializados, en vez de cargarle todo a la cámara, fue algo que aprendimos por las malas: la cámara ya tenía suficiente trabajo detectando pilares bajo luz variable, y si además le pedíamos distinguir las líneas del piso, se volvía poco confiable. Separar la percepción por dominio —color a la cámara, distancia lateral a los ToF, rumbo al giroscopio— hizo que todo el sistema fuera más robusto.

#### 4. Control de rumbo recto

Al principio pensamos que bastaba con "dejar el volante centrado" para que el robot avanzara recto. No es así: un volante centrado mecánicamente no garantiza una trayectoria recta, y cualquier desalineación —por mínima que sea— se va acumulando como deriva (de hecho, encontramos una causa mecánica concreta de esto; ver Bitácora, **Decisión 13**). Por eso cerramos el rumbo en lazo con el giroscopio: un controlador proporcional corrige el servo según el error entre el rumbo que queremos (`targetYaw`) y el que el giroscopio está midiendo. El movimiento del servo hacia esa corrección se hace de forma gradual (`servoSuave()`, con una velocidad de cambio limitada — `SERVO_SLEW`), para evitar bandazos bruscos en la dirección.

#### 5. Seguimiento de pilares (estado SEGUIR)

Cuando un pilar aparece con un tamaño mínimo en el cuadro (filtro `TAM_MIN`, para no perseguir manchas chiquitas o líneas del piso), el robot entra en SEGUIR y lo mantiene centrado con un controlador **proporcional-derivativo** que ajusta el servo según qué tan lejos está el pilar del centro real de la cámara (`CENTRO_IMG`, ya calibrado). El robot pasa de SEGUIR a la maniobra de esquive cuando el **alto del pilar en píxeles** supera un umbral (`H_ESQUIVAR`) — es decir, la señal de "ya está lo bastante cerca" viene del tamaño aparente en la cámara, no de un sensor de distancia dedicado.

- **Un error de signo bastante instructivo:** en una primera versión, el robot se **alejaba** del pilar en vez de seguirlo. Visto desde afuera parecía que estaba esquivando la caja, y al perderla de vista se enderezaba solo — se veía exactamente como un esquive, pero en realidad era el seguidor corrigiendo al revés. Bastó con invertir el signo del lazo de la cámara para que empezara a converger correctamente hacia el centro.
- Si el robot pierde de vista el pilar varios cuadros seguidos (`FRAMES_PERDIDO`) sin haber llegado a esquivar, regresa al estado RECTO.

#### 6. Decisión de sorteo: votación de color y maniobra comprometida (estado ESQUIVAR)

Esta fase concentró dos de las decisiones más importantes de todo el proyecto, y las dos salieron de fallos que vimos en pista y tuvimos que corregir.

**Votación de color durante la aproximación.** Al principio, el color del pilar se decidía justo en el momento en que el robot llegaba a la distancia de esquive. El problema es que, a quemarropa, el pilar llena toda la cámara y la clasificación de color se vuelve ruidosa. La solución fue ir acumulando "votos" de color durante toda la aproximación (`votosRojo`, `votosVerde`) —cuando el pilar todavía se ve a media distancia y el color es confiable— y decidir por mayoría justo antes de esquivar. Así, una sola lectura mala cerca del pilar ya no arruina la decisión.

**Comprometerse con una dirección, sin importar la posición.** El fallo más sutil de todos fue que el esquive seguía la *posición* del pilar en el cuadro en vez de comprometerse con una dirección fija: si el pilar entraba un poco cargado hacia un lado, el volante arrancaba hacia ese mismo lado, y terminábamos esquivando por el lado equivocado según dónde estuviera el pilar, no según su color. Lo arreglamos convirtiendo esta fase en una **decisión binaria, ciega a la posición** (`decideEsquive()`): si detecta rojo, el volante se compromete hacia la **derecha**; si es verde, hacia la **izquierda**; y si no logra identificar ningún color válido, suena una alarma. Una vez tomada la decisión, el volante se queda fijo por el resto de la maniobra, **sin volver a mirar la posición del pilar** — esto eliminó por completo los esquives por el lado equivocado.

La maniobra termina por distancia recorrida (odometría), por un ángulo máximo respecto al rumbo (`MAX_DODGE_ANGLE`, para evitar que el robot se quede dando vueltas) o por un tiempo límite de seguridad (`MAX_ESQUIVE_MS`); después de eso, pasa a REGRESAR, retoma el rumbo con `conduceRecto()` hasta alinearse dentro de una tolerancia (`TOL_RUMBO`) y vuelve a RECTO.

#### 7. Detección de esquinas

La detección de esquina se basa en algo simple: cuando el muro de un lado desaparece, el sensor de ese lado deja de leer una distancia corta y empieza a leer "abierto" (`LADO_LIBRE_CM`). Esta detección **solo se arma en estado RECTO**, y solo después de haberse alejado lo suficiente de la esquina anterior (`REARM_CM`), para no disparar dos veces por la misma esquina. En la práctica, este fue el subsistema que más vueltas nos dio.

- **Cómo decide el robot de qué lado están las esquinas:** como el sentido de la ronda es aleatorio, el robot lo resuelve solo al arrancar: se pega a la barrera exterior y promedia varias lecturas de los dos ToF; el sensor que ve **más lejos** apunta hacia el interior de la pista, que es justo el lado por donde se van a abrir las esquinas. Ese lado (`esquinaIzq`) queda fijo para toda la ronda, y así resolvimos de una sola vez la ambigüedad de horario/antihorario, sin necesitar leer ninguna línea del piso.
- **El alcance del sensor nos hizo perder tiempo:** durante las pruebas la detección era intermitente — a veces funcionaba, a veces no, a veces tarde. Al investigar encontramos que el VL53L0X, en su modo por defecto, solo es confiable hasta unos **50 cm** — muy por debajo de los más de **100 cm** que hacen falta para distinguir una esquina. Eso explicaba por qué el mismo sensor funcionaba perfecto siguiendo pared de cerca en el Open Challenge, pero fallaba al detectar la apertura. La solución fue activar el **modo de largo alcance** al inicializar el sensor, y confirmar la apertura con **varias lecturas seguidas** (`PROT_TOF`) antes de darla por buena, para descartar picos raros.
- **Y en su momento, el problema fue mecánico:** incluso con el modo correcto, la detección llegó a fallar en pista porque el sensor del lado abierto reportaba unos pocos centímetros donde debía leer "abierto". Encontramos que los sensores estaban ligeramente inclinados hacia el suelo — a simple vista parecían perpendiculares, pero los números decían otra cosa. **Este es el mismo tipo de problema que documentamos en la Bitácora, Decisión 12/13** (soportes de sensores laterales desalineados).

#### 8. Giro de esquina

Una vez armada y confirmada la apertura, el robot entra en modo "avanzando a la esquina": sigue derecho (con `conduceRecto()`) mientras decide, sensor en mano, **cómo y cuándo** ejecutar el giro.

- **Giro hacia adelante o en reversa.** Al confirmar la esquina, el robot mide la distancia al muro **exterior** (el lado contrario al de la esquina). Si ese muro está más lejos de lo normal (`DIST_REVERSA_CM`), el robot ejecuta la esquina **en reversa** (`giraEsquinaReversa()`: volante al lado contrario, motor hacia atrás, ángulo objetivo propio) en vez del giro normal hacia adelante (`giraEsquina()`). La lógica: cuando hay más espacio libre respecto al muro exterior, girar en reversa le da al robot un radio de giro efectivo más cerrado para tomar la esquina, en vez de necesitar el espacio adicional que exige un giro hacia adelante.
- **Qué dispara el momento exacto de girar.** Mientras avanza hacia el vértice, el robot revisa el sensor **ultrasónico frontal**: si detecta la pared dentro de una distancia calculada (que ya incluye el retraso propio del servo — ver punto 9), inicia el giro. Este es el método **principal**; si el ultrasónico no llega a dispararlo, hay un tope de seguridad por distancia recorrida (encoder) que fuerza el giro de todas formas, para que el robot nunca se quede avanzando indefinidamente hacia un muro que el ultrasónico no detectó a tiempo.
- **El giro por giroscopio, y el dolor de cabeza de los signos.** El giro se cierra en lazo con el giroscopio, y aquí vivimos la depuración más difícil de todo el proyecto: el volante tenía que girar físicamente hacia un lado mientras el giroscopio confirmaba esa misma rotación, y ambas cosas tenían que coincidir. La solución definitiva fue basar el fin del giro en el **cambio absoluto** de rumbo (la diferencia, en valor absoluto, entre el yaw actual y el inicial), sin importar el signo. Esta decisión eliminó de raíz toda una categoría de errores de signo que nos había costado muchísimas pruebas.
- **Retroceso después del giro.** Al terminar de girar, el robot retrocede un poco para recentrarse antes de seguir. Esta distancia puede ser **fija** (18 cm tras un giro normal, 13 cm tras uno en reversa) o, si se activa el modo adaptativo, calculada según qué tan lejos quedó el muro exterior después del giro — este segundo modo está implementado pero **desactivado** por ahora en el código.
- **Rumbo local por esquina.** Después de cada giro, el rumbo objetivo se reinicia a 0° — es decir, cada arista nueva "empieza de cero" en vez de acumular el rumbo de toda la vuelta, lo que evita que la deriva del giroscopio se acumule a lo largo de las tres vueltas.

#### 9. Auto-ajuste por perfil de servo

Como el servo de dirección del Obstacle Challenge (ST3215) permite fijar velocidad y aceleración, el código incluye un pequeño modelo del volante: a partir de las revoluciones por minuto de ficha del servo y el voltaje real con el que lo alimentamos, calcula cuántos grados por segundo gira realmente, y con eso, cuánto tarda (en milisegundos) en llegar a cualquier ángulo. Esa demora se traduce después a **centímetros que el robot ya avanzó mientras el volante todavía se estaba moviendo**, y esa distancia se le suma a los umbrales de esquive, de detección de esquina y de frenado — así, si en el futuro cambiamos de servomotor, basta con actualizar tres constantes (RPM de ficha, voltaje de ficha, voltaje real) y el resto de las distancias se recalculan solas. El propio programa además avisa por buzzer si, con el servo montado, el robot va demasiado rápido para el tiempo de reacción del volante.

#### 10. Ingeniería defensiva: tiempos de seguridad y protección del bus

Un principio que adoptamos tras varios episodios de bloqueo fue que **ninguna fase debe poder quedar atrapada indefinidamente**. En consecuencia, el giro, el esquive y la reincorporación disponen de **temporizadores de seguridad** que garantizan una salida aunque el sensor que normalmente cierra la fase falle. Del mismo modo, se le puso un **tiempo límite al bus I2C**: si un dispositivo compartido deja de responder, la comunicación corta la espera en lugar de congelar todo el programa. También la cámara HuskyLens tiene su propio chequeo al arrancar (varios intentos de conexión antes de darse por vencida y avisar por zumbador). Estas salvaguardas no sustituyen la corrección de la causa de fondo, pero convierten un fallo catastrófico (vehículo detenido o girando sin control) en una degradación acotada y recuperable.

#### 11. Odometría y separación de contadores

La odometría se calibró midiendo empíricamente los pulsos por centímetro del encoder. Un detalle de diseño surgido de la integración fue la necesidad de **dos contadores de distancia independientes**: uno para las distancias por fase (sorteo, avance a la esquina, giro), que se reinicia en cada transición, y otro para la distancia acumulada desde la última esquina, que gobierna el re-armado de la detección y que **no** debe reiniciarse cuando ocurre un sorteo entre dos esquinas. Sin esta separación, un sorteo a mitad de arista habría borrado la cuenta de re-armado y bloqueado la detección de la siguiente esquina.

#### 12. Metodología de desarrollo y decisiones revertidas

El desarrollo siguió una estrategia de **integración por capas**: cada subsistema (seguimiento, sorteo, rumbo, esquinas, salida de estacionamiento) se validó de forma aislada en su propio programa antes de unirse al conjunto, de manera que la depuración nunca enfrentara dos incógnitas a la vez.

Este método demostró su valor repetidamente, sobre todo al distinguir fallos reales de artefactos de prueba: varios comportamientos "erróneos" observados con el vehículo suspendido en el aire resultaron ser consecuencia inevitable de que las ruedas giraran sin que el chasis rotara (un artefacto de prueba análogo al descrito en la Bitácora, **Decisión 13**); la prueba correcta debía hacerse sobre el piso.

A modo de registro, las principales **decisiones revertidas o reemplazadas** durante el desarrollo de este algoritmo fueron:

| Decisión original | Reemplazada por | Motivo |
|---|---|---|
| Disparo de giro exclusivamente por odometría (encoder) | Disparo por ultrasónico frontal, con tope de seguridad por encoder | El encoder solo no distinguía con precisión el momento exacto de girar en aproximaciones distintas; el ultrasónico frontal, con el umbral ya compensado por el retraso del servo, es más preciso, y el encoder queda como respaldo de seguridad |
| Modo por defecto del VL53L0X | Modo de largo alcance (~2 m) | Alcance por defecto (~50 cm) insuficiente para detectar esquinas |
| Determinación de color a quemarropa | Votación de color durante la aproximación | Ruido de clasificación a corta distancia |
| Sorteo guiado por posición del pilar | Decisión binaria comprometida por color | Sorteos por el lado equivocado según posición, no color |
| Fin de giro basado en el signo del yaw | Fin de giro basado en el cambio absoluto de rumbo | Errores de signo que impedían completar el giro |

Cada una de estas reversiones se originó en una observación concreta de fallo y se resolvió atacando la **causa raíz** en lugar del síntoma, en línea con la filosofía de ingeniería que guio todo el proyecto.

<details>
<summary>📄 Ver código completo — Obstacle Challenge (<code>obstaculos.ino</code>)</summary>

```cpp
#include <Adafruit_VL53L0X.h>
#include <SCServo.h>
#include <Wire.h>
#include <MPU6050_light.h>
#include "HUSKYLENS.h"

MPU6050 mpu(Wire);
HUSKYLENS camara;
Adafruit_VL53L0X tofIzq = Adafruit_VL53L0X();   // IZQUIERDO  (0x31)
Adafruit_VL53L0X tofDer = Adafruit_VL53L0X();   // DERECHO    (0x30)

struct Blob { bool visto; int color; int x; int w; int h; };

// ---- Pines ----
const int STBY = 8, PWMA = 12, AIN1 = 10, AIN2 = 11;
const int ENC_PIN = 3;
const int XSHUT_IZQ = 7, XSHUT_DER = 6;
const int BUZZER = 49;
const int BOTON = 23;
const int TRIG_US = 5, ECHO_US = 4;

// ---- Servo direccion: Waveshare ST3215 (TTL en Serial1, pines 18/19) ----
SMS_STS st;
const int SERVO_ID   = 1;
int   VEL_SERVO  = 4095;   // velocidad del servo (max 4095)
int   ACEL_SERVO = 150;    // aceleracion (0-254)
const bool INVERTIR_DIR = true;   // el ST3215 gira al REVES del MG90S
// OJO: MIN debe ser SIEMPRE menor que MAX o constrain() se rompe
const int SERVO_CENTRO = 90, SERVO_MIN = 0, SERVO_MAX = 180;

int gradosApasos(float g) { return (int)(g * 4096.0 / 360.0 + 0.5); }
void mueveDir(float grados) {
  float g = INVERTIR_DIR ? (2.0 * SERVO_CENTRO - grados) : grados;
  st.WritePosEx(SERVO_ID, gradosApasos(g), VEL_SERVO, ACEL_SERVO);
}

// ========= PERFIL DEL SERVO: lo UNICO que cambias al cambiar de servomotor =========
float SERVO_RPM_SPEC = 52.0;   // RPM de ficha. C001=52 | C046=110 | MG90S=110
float SERVO_V_SPEC   = 7.4;    // voltaje al que aplica ese RPM (ficha)
float SERVO_V_REAL   = 7.5;    // voltaje con el que TU lo alimentas

// ========= PERFIL DEL ROBOT =========
float VEL_CM_S_REF = 29.0;     // cm/s MEDIDOS a PWM_REF (medido con el sketch de 100 cm)
int   PWM_REF      = 80;
bool  MIDE_VELOCIDAD = false;  // true = corre la medicion de velocidad y se detiene

// Fraccion de velocidad que realmente se le pide al ST3215
float fracVelServo() { return constrain((float)VEL_SERVO / 4095.0, 0.05, 1.0); }
// Velocidad angular efectiva del volante (grados/segundo)
float gradosPorSeg() { return SERVO_RPM_SPEC * (SERVO_V_REAL / SERVO_V_SPEC) * 6.0 * fracVelServo(); }
// Tiempo (ms) que tarda el volante en recorrer 'grados' (+30 ms de arranque)
unsigned long msServo(float grados) {
  return (unsigned long)((fabs(grados) / gradosPorSeg()) * 1000.0) + 30;
}
// Velocidad del robot (cm/s) a un PWM dado
float velRobot(int pwm) { return VEL_CM_S_REF * (float)pwm / (float)PWM_REF; }
// Distancia (cm) que avanza el robot MIENTRAS el volante llega al angulo
float lagCm(float grados, int pwm) { return velRobot(pwm) * msServo(grados) / 1000.0; }

// =================== CALIBRAR ===================
const int ID_ROJO = 1, ID_ROJO_2 = 3;
const int ID_VERDE = 2, ID_VERDE_2 = 4;
bool esRojo(int id)  { return id == ID_ROJO  || id == ID_ROJO_2;  }
bool esVerde(int id) { return id == ID_VERDE || id == ID_VERDE_2; }
int   CENTRO_IMG = 141;
int   SIGNO_CAM  = -1;
float Kp_seguir  = 0.6;
float Kd_seguir  = 1;
int   TAM_MIN    = 30;
int   MAX_ESQUIVE_STEER = 25;

// -- Esquive --
int   H_ESQUIVAR = 67;
int   ESQUIVE_STEER = 45;
float MAX_DODGE_ANGLE = 45;
int   FRAMES_PERDIDO = 4;
float MAX_ESQUIVE_MS = 4000;
float MAX_REGRESO_MS = 4000;

// -- Rumbo / regreso --
int   SIGNO_RUMBO = 1;
float Kp_head     = 2.0;
float TOL_RUMBO   = 1;   // NO poner 0: fabs()<0 nunca se cumple y bloquea la salida de REGRESAR
int   SERVO_SLEW  = 6;

// -- Corners --
float LADO_LIBRE_CM  = 180;
int   PROT_TOF       = 3;
float AVANCE_CORNER_CM = 80;   // TOPE de seguridad por encoder (giro normal)
float REARM_CM = 140;
float RETROCESO_POST_GIRO_CM = 18;
bool  CORNER_POR_ULTRASONICO = true;

// -- Retroceso adaptativo --
bool  RETRO_ADAPTATIVO = false;
float DIST_MURO_REF = 28;
float K_RETRO       = 0.8;
float RETRO_MAX_CM  = 25;

// -- Giro en REVERSA --
bool  GIRO_REVERSA_ON = true;
float DIST_REVERSA_CM = 80;
float AVANCE_MAX_REVERSA_CM = 130;   // TOPE de seguridad por encoder (giro en reversa)
float RETROCESO_POST_REVERSA_CM = 13;
float ANGULO_GIRO_REVERSA = 86;      // manual: depende de la inercia, NO del servo

float ANGULO_GIRO = 88;              // manual: depende de la inercia, NO del servo
int   VEL_GIRO    = 60;
int   VEL_ESPACIO = 110;
int   PULSOS_ESPACIO = 13;
float MAX_GIRO_MS = 3000;

// -- Arranque --
long  ROT_RETROCESO_INICIAL = 400;
int   VEL_RETROCESO_INI = 80;

// -- Odometria / velocidad / meta --
float PULSOS_POR_CM = 20.0;
int   VEL       = 80;
int   VEL_RECUP = 75;
int   TOTAL_GIROS = 12;

// ===== DISTANCIAS BASE (valor si el servo fuera instantaneo) =====
// Estas NO se tocan al cambiar de servo: el lag se suma solo.
float ESQUIVE_CM_BASE           = 25;
float DIST_FRONTAL_CORNER_BASE  = 55;
float DIST_FRONTAL_REVERSA_BASE = 15;
float DIST_RECUP_BASE           = 8;

// ===== DISTANCIAS EFECTIVAS (se recalculan solas segun el servo montado) =====
float esquiveCm()          { return ESQUIVE_CM_BASE           + lagCm(ESQUIVE_STEER, VEL); }
float distFrontalCorner()  { return DIST_FRONTAL_CORNER_BASE  + lagCm(SERVO_MAX - SERVO_CENTRO, VEL); }
float distFrontalReversa() { return DIST_FRONTAL_REVERSA_BASE + lagCm(SERVO_CENTRO - SERVO_MIN, VEL); }
float distRecupCm()        { return DIST_RECUP_BASE           + lagCm(ESQUIVE_STEER, VEL_RECUP); }
// ===============================================

// --------- Estado ---------
volatile long encCount = 0;
volatile long encCorner = 0;
float yaw = 0, gyroZoffset = 0, targetYaw = 0;
unsigned long lastYawUs = 0, lastCamMs = 0, lastTofMs = 0, lastLog = 0;
float lastI = 999, lastD = 999, ladoEsqCm = 999;
int servoPos = SERVO_CENTRO;
int perdidos = 0, giros = 0, cntEsq = 0;
int colorEsquive = ID_ROJO, servoDodge = SERVO_CENTRO;
int votosRojo = 0, votosVerde = 0;
float errPrev = 0;
unsigned long tFase = 0;
bool avanzandoGiro = false, esquinaIzq = true;
bool giroEnReversa = false;

enum Fase { RECTO, SEGUIR, ESQUIVAR, REGRESAR };
Fase fase = RECTO;

Blob blobActual = {false, 0, 0, 0, 0};

void onEnc() { encCount++; encCorner++; }

void setup() {
  Serial.begin(115200);
  Wire.begin();
  pinMode(BOTON, INPUT_PULLUP);
  Wire.setWireTimeout(3000, true);
  pinMode(ENC_PIN, INPUT_PULLUP);
  attachInterrupt(digitalPinToInterrupt(ENC_PIN), onEnc, RISING);
  pinMode(STBY, OUTPUT); pinMode(PWMA, OUTPUT); pinMode(AIN1, OUTPUT); pinMode(AIN2, OUTPUT);
  digitalWrite(STBY, LOW);
  pinMode(XSHUT_IZQ, OUTPUT); pinMode(XSHUT_DER, OUTPUT);
  pinMode(TRIG_US, OUTPUT); pinMode(ECHO_US, INPUT);

  // ---- ST3215 ----
  Serial1.begin(1000000);
  st.pSerial = &Serial1;
  delay(500);
  if (st.Ping(SERVO_ID) == -1) {
    Serial.println(F("ST3215 no responde. Revisa cables / alimentacion / ID."));
    tone(BUZZER, 200, 400);
  }
  mueveDir(SERVO_CENTRO); servoPos = SERVO_CENTRO;
  delay(msServo(90));

  // ---- Medicion de velocidad (opcional) ----
  if (MIDE_VELOCIDAD) {
    Serial.println(F("MIDIENDO VELOCIDAD: 3 s a VEL. Deja pista libre."));
    delay(2000);
    resetDist(); motor(VEL); delay(3000); motor(0);
    Serial.print(F("VEL_CM_S medida = ")); Serial.println(distanciaCm() / 3.0, 1);
    Serial.println(F("-> ponla en VEL_CM_S_REF y regresa MIDE_VELOCIDAD a false"));
    while (true) {}
  }

  // ---- Reporte del auto-ajuste ----
  Serial.println(F("===== AUTO-AJUSTE ====="));
  Serial.print(F("servo: ")); Serial.print(SERVO_RPM_SPEC, 0); Serial.print(F(" RPM -> "));
  Serial.print(gradosPorSeg(), 0); Serial.println(F(" deg/s"));
  Serial.print(F("robot: ")); Serial.print(velRobot(VEL), 1); Serial.println(F(" cm/s"));
  Serial.print(F("esquive=")); Serial.print(esquiveCm(), 1);
  Serial.print(F("  frontalCorner=")); Serial.print(distFrontalCorner(), 1);
  Serial.print(F("  frontalRev=")); Serial.print(distFrontalReversa(), 1);
  Serial.print(F("  recup=")); Serial.println(distRecupCm(), 1);
  if (lagCm(ESQUIVE_STEER, VEL) > ESQUIVE_CM_BASE * 0.6) {
    Serial.println(F("AVISO: el robot va rapido para este servo. Baja VEL o usa servo mas rapido."));
    tone(BUZZER, 300, 400); delay(500);
  }
  Serial.println(F("======================="));

  byte mpuStatus = mpu.begin(); while (mpuStatus != 0) { mpuStatus = mpu.begin(); }
  mpu.calcOffsets();
  calibraGiroZ();
  lastYawUs = micros();

  // ToF en LARGO ALCANCE
  digitalWrite(XSHUT_IZQ, LOW); digitalWrite(XSHUT_DER, LOW); delay(10);
  digitalWrite(XSHUT_DER, HIGH); delay(10);
  tofDer.begin(0x30, false, &Wire, Adafruit_VL53L0X::VL53L0X_SENSE_LONG_RANGE);
  digitalWrite(XSHUT_IZQ, HIGH); delay(10);
  tofIzq.begin(0x31, false, &Wire, Adafruit_VL53L0X::VL53L0X_SENSE_LONG_RANGE);

  // Camara
  while (!camara.begin(Wire)) {
    Serial.println(F("No conecta la HuskyLens (Protocol Type = I2C)"));
    delay(200);
  }
  delay(200);
  camara.writeAlgorithm(ALGORITHM_COLOR_RECOGNITION);
  delay(200);
  camara.writeAlgorithm(ALGORITHM_COLOR_RECOGNITION);
  bool camOK = false;
  for (int i = 0; i < 40; i++) { if (camara.request()) { camOK = true; break; } delay(50); }
  if (!camOK) { while (true) { tone(BUZZER, 200, 300); delay(600); } }
  tone(BUZZER, 1500, 100); delay(130); tone(BUZZER, 1500, 100);

  yaw = 0; targetYaw = 0;
  delay(400);

  // ---- Lado de esquina: el que ve mas lejos al arrancar ----
  float sumI = 0, sumD = 0;
  for (int i = 0; i < 10; i++) { leeTof(); sumI += lastI; sumD += lastD; delay(30); }
  esquinaIzq = (sumI >= sumD);
  Serial.print(F("izq_prom=")); Serial.print(sumI / 10, 0);
  Serial.print(F("  der_prom=")); Serial.print(sumD / 10, 0);
  Serial.print(F("  -> LADO DE ESQUINA = "));
  Serial.println(esquinaIzq ? F("IZQUIERDA") : F("DERECHA"));
  if (esquinaIzq) { tone(BUZZER, 1200, 120); delay(180); tone(BUZZER, 1200, 120); }
  else            { tone(BUZZER, 700, 250); }
  delay(600);

  yaw = 0; targetYaw = 0;

  // ---- Espera el boton de arranque ----
  Serial.println(F("Listo. Esperando boton de arranque..."));
  while (digitalRead(BOTON) == LOW) { delay(10); }
  delay(50);
  tone(BUZZER, 1500, 200);
  yaw = 0; targetYaw = 0;

  MotorEncPulsos(-VEL_RETROCESO_INI, ROT_RETROCESO_INICIAL);
  resetDist(); resetCorner();
}

void loop() {
  actualizaYaw();

  if (millis() - lastCamMs > 33) { blobActual = leeCamara(); lastCamMs = millis(); }
  Blob b = blobActual;

  // fase: 0=RECTO 1=SEGUIR 2=ESQUIVAR 3=REGRESAR 9=girando
  if (millis() - lastLog > 300) {
    lastLog = millis();
    Serial.print(F("fase=")); Serial.print(avanzandoGiro ? 9 : (int)fase);
    Serial.print(F("  ID=")); Serial.print(b.visto ? b.color : -1);
    Serial.print(F("  h=")); Serial.print(b.visto ? b.h : -1);
    Serial.print(F("  ladoEsq=")); Serial.print(ladoEsqCm, 0);
    Serial.print(F("  yaw=")); Serial.print(yaw, 1);
    Serial.print(F("  dist=")); Serial.print(distanciaCm(), 0);
    Serial.print(F("  giros=")); Serial.println(giros);
  }

  // ===== CORNER en curso: avanzar y girar (maxima prioridad) =====
  if (avanzandoGiro) {
    conduceRecto();
    motor(VEL);
    bool listoParaGirar = false;
    bool porUltrasonico = false;
    if (giroEnReversa) {
      float dFrontal = leeUltrasonico();
      if (dFrontal <= distFrontalReversa())            { listoParaGirar = true; porUltrasonico = true; }
      else if (distanciaCm() >= AVANCE_MAX_REVERSA_CM)   listoParaGirar = true;
    } else if (CORNER_POR_ULTRASONICO) {
      float dFrontal = leeUltrasonico();
      if (dFrontal <= distFrontalCorner())             { listoParaGirar = true; porUltrasonico = true; }
      else if (distanciaCm() >= AVANCE_CORNER_CM)        listoParaGirar = true;
    } else {
      listoParaGirar = (distanciaCm() >= AVANCE_CORNER_CM);
    }
    if (listoParaGirar) {
      if (porUltrasonico) {
        if (giroEnReversa) { tone(BUZZER, 2200, 60); delay(70); tone(BUZZER, 2200, 60); }
        else               { tone(BUZZER, 1800, 90); }
      } else {
        tone(BUZZER, 350, 200);   // tope por encoder: el ultrasonico NO vio la pared
      }
      if (giroEnReversa) giraEsquinaReversa(esquinaIzq);
      else               giraEsquina(esquinaIzq);
      giros++;
      avanzandoGiro = false;
      resetDist(); resetCorner();
      if (giros >= TOTAL_GIROS) { freno(); tone(BUZZER, 1500, 500); while (true) {} }
    }
    return;
  }

  // ===== Deteccion de esquina: SOLO en RECTO =====
  if (fase == RECTO && millis() - lastTofMs > 50) {
    lastTofMs = millis();
    ladoEsqCm = leeTofEsquina();
    if (giros == 0 || distDesdeCorner() >= REARM_CM) {
      if (ladoEsqCm >= LADO_LIBRE_CM) cntEsq++; else cntEsq = 0;
      if (cntEsq >= PROT_TOF) {
        avanzandoGiro = true; resetDist(); cntEsq = 0;
        float dMuroDet = leeTofExterno();
        giroEnReversa = (GIRO_REVERSA_ON && dMuroDet > DIST_REVERSA_CM);
        Serial.print(F(">> esquina ")); Serial.print(esquinaIzq ? F("IZQ") : F("DER"));
        Serial.print(F("  muroExt=")); Serial.print(dMuroDet, 0);
        Serial.println(giroEnReversa ? F("  -> GIRO EN REVERSA") : F("  -> giro normal"));
        tone(BUZZER, giroEnReversa ? 1400 : 880, 120);
        return;
      }
    } else cntEsq = 0;
  }

  // ===== Maquina de estados del esquive =====
  switch (fase) {

    case RECTO:
      conduceRecto();
      motor(VEL);
      if (b.visto) { fase = SEGUIR; perdidos = 0; votosRojo = 0; votosVerde = 0; errPrev = 0; }
      break;

    case SEGUIR:
      if (b.visto) {
        seguidor(b);
        if (esRojo(b.color)) votosRojo++; else if (esVerde(b.color)) votosVerde++;
        perdidos = 0;
        if (b.h > H_ESQUIVAR) {
          colorEsquive = (votosRojo >= votosVerde) ? ID_ROJO : ID_VERDE;
          decideEsquive();
          fase = ESQUIVAR; resetDist(); tFase = millis();
        }
      } else {
        perdidos++;
        mueveDir(servoPos);
        if (perdidos >= FRAMES_PERDIDO) fase = RECTO;
      }
      motor(VEL);
      break;

    case ESQUIVAR:
      servoSuave(servoDodge);
      motor(VEL);
      if (distanciaCm() >= esquiveCm() || fabs(yaw - targetYaw) > MAX_DODGE_ANGLE
          || millis() - tFase > MAX_ESQUIVE_MS) {
        Serial.print(F("<< fin esquive dist=")); Serial.println(distanciaCm());
        fase = REGRESAR; resetDist(); tFase = millis();
      }
      break;

    case REGRESAR:
      
      conduceRecto();
      motor(VEL_RECUP);
      if ((distanciaCm() >= distRecupCm() && fabs(targetYaw - yaw) < TOL_RUMBO)
          || millis() - tFase > MAX_REGRESO_MS) {
        fase = RECTO;
      }
      break;
  }
}

// ===== Decision binaria =====
void decideEsquive() {
  if (colorEsquive == ID_ROJO) {
    servoDodge = SERVO_CENTRO + ESQUIVE_STEER;      // rojo -> DERECHA
    Serial.print(F(">> ESQUIVA ROJO (derecha)"));
    tone(BUZZER, 400, 80);
  } else if (colorEsquive == ID_VERDE) {
    servoDodge = SERVO_CENTRO - ESQUIVE_STEER;      // verde -> IZQUIERDA
    Serial.print(F(">> ESQUIVA VERDE (izquierda)"));
    tone(BUZZER, 700, 80);
  } else {
    servoDodge = SERVO_CENTRO;
    Serial.print(F(">> COLOR DESCONOCIDO"));
    tone(BUZZER, 4000, 250);
  }
  Serial.print(F("  [votos R=")); Serial.print(votosRojo);
  Serial.print(F(" V=")); Serial.print(votosVerde); Serial.println(F("]"));
}

// ===== Giro normal (mide cambio ABSOLUTO de yaw: a prueba de signos) =====
void giraEsquina(bool haciaIzq) {
  MotorEncPulsos(-VEL_ESPACIO, PULSOS_ESPACIO);
  // Si gira al lado contrario, invierte SOLO esta linea (SERVO_MAX <-> SERVO_MIN)
  int lock = haciaIzq ? SERVO_MAX : SERVO_MIN;
  mueveDir(lock); servoPos = lock;
  delay(msServo(fabs(lock - SERVO_CENTRO)));           // espera EXACTA segun el servo montado
  float yawStart = yaw;
  motor(VEL_GIRO);
  unsigned long t0 = millis();
  while (true) {
    actualizaYaw();
    if (fabs(yaw - yawStart) >= ANGULO_GIRO) break;
    if (millis() - t0 > MAX_GIRO_MS) { Serial.println(F("   [timeout giro]")); break; }
  }
  motor(0);
  targetYaw = yaw;

  mueveDir(SERVO_CENTRO); servoPos = SERVO_CENTRO;
  delay(msServo(fabs(lock - SERVO_CENTRO)));

  if (RETRO_ADAPTATIVO) {
    float dMuro = leeTofExterno();
    float retro = (DIST_MURO_REF - dMuro) * K_RETRO;
    retro = constrain(retro, 0, RETRO_MAX_CM);
    Serial.print(F("   muroExt=")); Serial.print(dMuro, 0);
    Serial.print(F("  retro=")); Serial.println(retro, 0);
    if (retro > 1) retrocedeCentrado(retro);
  } else {
    if (RETROCESO_POST_GIRO_CM > 0) retrocedeCentrado(RETROCESO_POST_GIRO_CM);
  }

  // Rumbo LOCAL: la nueva arista arranca en 0
  yaw = 0; targetYaw = 0;
}

// ===== Giro en REVERSA: volante al lado CONTRARIO y motor en reversa =====
void giraEsquinaReversa(bool haciaIzq) {
  int lock = haciaIzq ? SERVO_MIN : SERVO_MAX;
  mueveDir(lock); servoPos = lock;
  delay(msServo(fabs(lock - SERVO_CENTRO)));
  float yawStart = yaw;
  motor(-VEL_GIRO);                                    // <-- REVERSA
  unsigned long t0 = millis();
  while (true) {
    actualizaYaw();
    if (fabs(yaw - yawStart) >= ANGULO_GIRO_REVERSA) break;
    if (millis() - t0 > MAX_GIRO_MS) { Serial.println(F("   [timeout giro reversa]")); break; }
  }
  motor(0);
  targetYaw = yaw;

  mueveDir(SERVO_CENTRO); servoPos = SERVO_CENTRO;
  delay(msServo(fabs(lock - SERVO_CENTRO)));

  if (RETROCESO_POST_REVERSA_CM > 0) retrocedeCentrado(RETROCESO_POST_REVERSA_CM);

  yaw = 0; targetYaw = 0;
}

// Retrocede una distancia con el volante clavado en el centro.
void retrocedeCentrado(float cm) {
  mueveDir(SERVO_CENTRO); servoPos = SERVO_CENTRO;
  delay(msServo(90));
  resetDist();
  motor(-VEL_RETROCESO_INI);
  unsigned long t0 = millis();
  while (distanciaCm() < cm && millis() - t0 < 2000) { }
  motor(0);
  mueveDir(SERVO_CENTRO); servoPos = SERVO_CENTRO;
  delay(80);
}

void MotorEncPulsos(int velocidad, int pulsos) {
  resetDist();
  motor(velocidad);
  unsigned long t0 = millis();
  while (encCount <= pulsos && millis() - t0 < 1000) {}
  motor(0);
}

// ===== Seguidor: lleva el objeto al centro (PD) =====
void seguidor(Blob b) {
  float err = CENTRO_IMG - b.x;
  float d = err - errPrev;
  float salida = Kp_seguir * err + Kd_seguir * d;
  errPrev = err;
  salida = constrain(salida, -MAX_ESQUIVE_STEER, MAX_ESQUIVE_STEER);
  int servo = SERVO_CENTRO + SIGNO_CAM * (int)salida;
  mueveDir(servo); servoPos = servo;
}

// ===== Camara =====
Blob leeCamara() {
  Blob b = {false, 0, 0, 0, 0};
  if (!camara.request()) return b;
  long mejorArea = -1;
  while (camara.available()) {
    HUSKYLENSResult r = camara.read();
    if (r.command != COMMAND_RETURN_BLOCK) continue;
    int w = r.width, h = r.height;
    if (!esRojo(r.ID) && !esVerde(r.ID)) continue;
    if (min(w, h) < TAM_MIN) continue;
    long area = (long)w * h;
    if (area > mejorArea) {
      mejorArea = area;
      b.visto = true; b.color = r.ID; b.x = r.xCenter; b.w = w; b.h = h;
    }
  }
  return b;
}

// ===== Rumbo recto =====
void conduceRecto() {
  float err = targetYaw - yaw;
  int salida = SERVO_CENTRO + SIGNO_RUMBO * (int)(Kp_head * err);
  salida = constrain(salida, SERVO_MIN, SERVO_MAX);
  servoSuave(salida);
}
void servoSuave(int objetivo) {
  objetivo = constrain(objetivo, SERVO_MIN, SERVO_MAX);
  if (objetivo > servoPos)      servoPos = min(servoPos + SERVO_SLEW, objetivo);
  else if (objetivo < servoPos) servoPos = max(servoPos - SERVO_SLEW, objetivo);
  mueveDir(servoPos);
}

void actualizaYaw() {
  mpu.update();
  unsigned long now = micros();
  float dt = (now - lastYawUs) / 1000000.0;
  lastYawUs = now;
  if (dt < 0 || dt > 0.2) dt = 0;
  yaw += (mpu.getGyroZ() - gyroZoffset) * dt;
}
void calibraGiroZ() {
  float s = 0;
  for (int i = 0; i < 500; i++) { mpu.update(); s += mpu.getGyroZ(); delay(3); }
  gyroZoffset = s / 500.0;
}

// ===== Sensores ToF =====
void leeTof() {
  VL53L0X_RangingMeasurementData_t m;
  tofIzq.rangingTest(&m, false);
  lastI = (m.RangeStatus == 4) ? 999.0 : m.RangeMilliMeter / 10.0;
  tofDer.rangingTest(&m, false);
  lastD = (m.RangeStatus == 4) ? 999.0 : m.RangeMilliMeter / 10.0;
}
float leeTofEsquina() {
  VL53L0X_RangingMeasurementData_t m;
  if (esquinaIzq) tofIzq.rangingTest(&m, false);
  else            tofDer.rangingTest(&m, false);
  return (m.RangeStatus == 4) ? 999.0 : m.RangeMilliMeter / 10.0;
}
float leeTofExterno() {
  VL53L0X_RangingMeasurementData_t m;
  if (esquinaIzq) tofDer.rangingTest(&m, false);
  else            tofIzq.rangingTest(&m, false);
  return (m.RangeStatus == 4) ? 999.0 : m.RangeMilliMeter / 10.0;
}

// Lee el ULTRASONICO frontal (cm). Sin eco -> 999 (lejos).
float leeUltrasonico() {
  digitalWrite(TRIG_US, LOW);  delayMicroseconds(2);
  digitalWrite(TRIG_US, HIGH); delayMicroseconds(10);
  digitalWrite(TRIG_US, LOW);
  long dur = pulseIn(ECHO_US, HIGH, 25000);
  if (dur == 0) return 999.0;
  return dur / 58.0;
}

float distanciaCm()     { return encCount  / PULSOS_POR_CM; }
float distDesdeCorner() { return encCorner / PULSOS_POR_CM; }
void  resetDist()   { noInterrupts(); encCount  = 0; interrupts(); }
void  resetCorner() { noInterrupts(); encCorner = 0; interrupts(); }

// ===== Motor =====
void motor(int v) {
  digitalWrite(STBY, HIGH);
  if (v >= 0) { digitalWrite(AIN1, HIGH); digitalWrite(AIN2, LOW); }
  else        { digitalWrite(AIN1, LOW);  digitalWrite(AIN2, HIGH); v = -v; }
  analogWrite(PWMA, constrain(v, 0, 255));
}
void freno() { analogWrite(PWMA, 0); digitalWrite(STBY, LOW); }
```

</details>

## 4. Pensamiento Sistémico y Decisiones de Ingeniería
 
> [!NOTE]
> Esta sección documenta, en orden cronológico, el **razonamiento detrás de cada cambio importante** en el robot: el problema o restricción que lo motivó, las alternativas consideradas, la decisión tomada y la evidencia que la respalda. El objetivo es mostrar el proceso de ingeniería completo, no solo el resultado final.
 
Cada entrada sigue el mismo formato: **Contexto/Restricción → Opciones consideradas → Decisión y justificación → Evidencia/Resultado**.
 
### Resumen rápido
 
| # | Fecha | Decisión | Categoría | Estado |
|---|---|---|---|---|
| 1 | Inicio de temporada (s/f) | RPi + Pure Pursuit para evasión de obstáculos | Software |  (ver 10) |
| 2 | 21 may 2026 | Raspberry Pi → HuskyLens + Arduino Mega | Software/Hardware |  |
| 3 | s/f | Ruedas 62.4×20 mm → 57×14 mm | Mecánico |  |
| 4 | s/f | Baterías 6×3.7 V → 2×7.8 V/2200 mAh | Potencia |  (comparando alternativa 7.4 V/3000 mAh) |
| 5 | Antes del regional | VL53L0X probado, no usado en el regional | Sensores |  (ver 8) |
| 6 | 25 jun 2026 | Falla eléctrica (regulador + servo) | Riesgo/Mantenimiento |  |
| 7 | 28 jun 2026 | Sensor de esquina IR + validación Open Round | Sensores |  |
| 8 | 5 jul 2026 | Sensores laterales: ultrasónico → VL53L0X | Sensores |  |
| 9 | 5 jul 2026 | Curvas: giroscopio → seguimiento de muro | Software |  |
| 10 | Post-regional (s/f exacta) | Evasión: Pure Pursuit → reactivo por distancia | Software |  |
| 11 | 7 jul 2026 | Validación de evasión de obstáculos | Pruebas |  (solo tramo recto) |
| 12 | 26 jul – 9 ago 2026 | Falla de montaje en soportes de sensores laterales → rediseño e impresión de soporte definitivo | Mecánico |  |
| 13 | 3 ago 2026 | Corrección de deriva: orificio de eje mal dimensionado en soporte impreso del motor | Mecánico |  |
| 14 | 9 ago 2026 | Recalibración de umbrales de evasión + validación en ¾ de vuelta | Software/Pruebas |  |
| 15 | 10 ago 2026 | Descontinuación del sensor infrarrojo de esquina | Sensores |  |
| 16 | 23 ago 2026 | Corrida completa del Obstacle Challenge (2 min 18 s) | Pruebas |  |
 
### Decisión 1 — Arquitectura inicial de evasión de obstáculos: Raspberry Pi + Pure Pursuit
 
- **Contexto/Restricción:** el sistema de evasión de obstáculos dependía inicialmente de maniobras preprogramadas y casos específicos, lo cual limitaba la adaptabilidad del robot ante distintas posiciones de obstáculos.
- **Decisión:** implementar un sistema de seguimiento de trayectoria basado en **Pure Pursuit**, usando la cámara Raspberry Pi Rev 1.3 como sensor principal de percepción. El algoritmo detectaba la posición del obstáculo, generaba puntos de trayectoria alrededor de este y seleccionaba continuamente un punto adelantado sobre la trayectoria para calcular el ángulo de dirección necesario.
- **Resultado:** el enfoque generó movimientos más suaves que las maniobras fijas, pero incrementó la complejidad y la carga de procesamiento del sistema (ver Decisión 2 y Decisión 10).
### Decisión 2 — Cambio de plataforma de visión: Raspberry Pi → HuskyLens (21 de mayo de 2026)
 
- **Contexto/Restricción:** la Raspberry Pi + cámara Raspberry Pi ofrecía resultados funcionales, pero incrementaba la complejidad general del sistema y requería mayor carga de procesamiento para ejecutar los algoritmos de detección.
- **Opciones consideradas:** optimizar el pipeline de visión sobre Raspberry Pi vs. migrar a un sensor de visión dedicado con modos de reconocimiento preconfigurados.
- **Decisión y justificación:** se reemplazaron la Raspberry Pi y su cámara por una **cámara HuskyLens**, dejando al **Arduino Mega** como único controlador. La HuskyLens simplifica el desarrollo del sistema de detección (funciones de visión artificial integradas) y libera al Arduino Mega para tareas de control y navegación, mejorando la capacidad de reacción durante maniobras dinámicas.
- **Evidencia/Resultado:** HuskyLens integrada desde el 21 de mayo de 2026; se continúa calibrando y evaluando los distintos modos de reconocimiento de la cámara.
### Decisión 3 — Rediseño de ruedas y footprint
 
- **Contexto/Restricción:** las ruedas anteriores (62.4 × 20 mm) ofrecían buena estabilidad pero incrementaban el tamaño general del robot.
- **Opciones consideradas:** mantener las ruedas actuales vs. adoptar un modelo más pequeño (Lego Spike Prime, 57 × 14 mm).
- **Decisión y justificación:** se sustituyeron las ruedas por el modelo de 57 × 14 mm. Estas ruedas tienen un coeficiente de desgaste más alto, lo que mejora la durabilidad y el agarre en superficies de competencia; su menor tamaño también reduce dimensiones y peso.
- **Evidencia/Resultado:** altura reducida de 23.9 cm a 20.3 cm; ancho de 15 cm a 14.6 cm. La estructura resultante es más compacta y ligera, con un centro de gravedad ligeramente mejorado que favorece la estabilidad en curvas y maniobras rápidas.
### Decisión 4 — Simplificación del sistema de alimentación
 
- **Contexto/Restricción:** el arreglo anterior de 6 baterías de 3.7 V (~12 V, 2000 mAh) cumplía los requerimientos energéticos, pero ocupaba mucho espacio interno y aumentaba el peso del robot.
- **Opciones consideradas:** mantener el arreglo de 6 celdas vs. consolidar en menos celdas de mayor voltaje.
- **Decisión y justificación:** se adoptaron **2 baterías de 7.8 V, 2200 mAh**, liberando espacio interno, reduciendo peso y simplificando la gestión energética.
- **Evidencia/Resultado:** reducción de espacio y peso confirmada, con autonomía suficiente para completar las rondas. **Iteración en curso:** en paralelo se evalúa un segundo conjunto de baterías (7.4 V, 3000 mAh), más ligero y compacto pero de menor voltaje, comparándolo contra el actual en autonomía, estabilidad eléctrica bajo carga del motor, peso y desempeño en pista. El arreglo de 7.8 V / 2200 mAh se mantiene como configuración vigente mientras la comparación no arroje una ventaja clara del otro.
### Decisión 5 — Prueba experimental del sensor VL53L0X (no desplegado en el regional)
 
- **Contexto/Restricción:** el sensor láser VL53L0X (Time-of-Flight) se integró de forma experimental en la arquitectura electrónica para mejorar la detección frontal de obstáculos y la precisión a corta distancia.
- **Decisión de mitigación de riesgo:** debido a limitaciones de tiempo durante la integración y calibración, el equipo decidió **no utilizar el sensor durante la competencia regional**, priorizando la confiabilidad del sistema sobre la incorporación de un componente insuficientemente probado.
- **Resultado:** el sensor se documentó como una mejora importante para futuras iteraciones y se integró de forma permanente después del regional (ver Decisión 8).
### Decisión 6 — Incidente eléctrico y respuesta a falla (25 de junio de 2026)
 
- **Contexto:** durante las pruebas, el regulador de voltaje y el servomotor de dirección (MG90S) sufrieron un corto circuito y resultaron dañados.
- **Impacto:** las pruebas de navegación se detuvieron temporalmente mientras se diagnosticaba el origen de la falla.
- **Acción de mitigación:** reemplazo de ambos componentes y revisión del cableado y las conexiones asociadas, con el objetivo de evitar que la falla se repita.
- **Estado:** Resuelto con el debido cambio de componentes.
### Decisión 7 — Sensor de esquina trasero y validación con pruebas de vuelta abierta (28 de junio de 2026)
 
- **Contexto/Restricción:** el robot no contaba con un sensor dedicado a detectar las líneas de las esquinas de la pista, lo que podía generar imprecisiones al iniciar o finalizar una maniobra de giro.
- **Decisión y justificación:** se incorporó un sensor infrarrojo **MH Sensor Series** (basado en TCRT5000 con comparador LM393) en el extremo trasero inferior, complementando la información de los sensores laterales VL53L0X y el algoritmo de seguimiento de muro.
- **Evidencia/Resultado:** en las pruebas de vuelta abierta del mismo día, el robot completó **3 vueltas de forma consistente**, se estacionó correctamente en el cuadrante de inicio y completó el recorrido en **75 segundos**, validando en conjunto los sensores VL53L0X laterales, el seguimiento de muro y el nuevo sensor de esquina. Ver video en la sección [Open Challenge](#open-challenge).
### Decisión 8 — Sensores laterales: de ultrasónico a VL53L0X ToF (5 de julio de 2026)
 
- **Contexto/Restricción:** los sensores ultrasónicos (HC-SR04P) usados en los laterales eran susceptibles a variaciones de lectura según el ángulo o el material del muro.
- **Opciones consideradas:** mantener los sensores ultrasónicos vs. desplegar de forma definitiva el VL53L0X, ya validado experimentalmente (Decisión 5) pero no usado en el regional por límites de tiempo.
- **Decisión y justificación:** se sustituyeron los sensores laterales ultrasónicos por **VL53L0X ToF**, que al basarse en luz infrarroja ofrecen mediciones más estables y consistentes a corta distancia que la reflexión de ondas sonoras.
- **Resultado:** el VL53L0X pasa a formar parte permanente de la arquitectura electrónica, específicamente en los laterales.
### Decisión 9 — Navegación en curvas: de giroscopio a seguimiento de muro

- **Contexto/Restricción:** el robot resolvía todo el Open Challenge apoyado en un solo sensor: el giroscopio (GY-9250). Avanzaba recto manteniendo un rumbo y giraba las esquinas contra ese mismo rumbo. El problema de fondo es que el giroscopio estima el ángulo **integrando** la velocidad angular, así que su error se acumula con el tiempo y crece con la velocidad: entre más rápido iba el robot, más rápido se degradaba su estimación de rumbo y más se desviaba de la trayectoria. Eso nos obligaba a **bajar la velocidad del robot** para que el giroscopio alcanzara a mantener un rumbo confiable — estábamos pagando velocidad para comprar precisión.
- **Opciones consideradas:** seguir bajando la velocidad y afinando la calibración del giroscopio, o cambiar a una referencia **absoluta** en lugar de una acumulativa: medir directamente la distancia al muro exterior con los sensores VL53L0X (Decisión 8).
- **Decisión y justificación:** migramos a un esquema de **seguimiento de muro**, donde el sistema mide constantemente la distancia al muro exterior y corrige la dirección para mantenerla constante. A diferencia del rumbo por giroscopio, esta medición **no acumula error**: cada lectura es independiente y se refiere a algo físico y fijo (el muro), así que un mal dato no contamina los siguientes. Eso eliminó la razón por la que teníamos que ir despacio.
- **Evidencia/Resultado:** con el esquema anterior, dependiendo únicamente del giroscopio, el mejor tiempo del Open Challenge era de **95 segundos**. Al migrar al seguimiento de muro pudimos **subir la velocidad del robot** sin perder precisión de trayectoria, bajando el recorrido a **75 segundos** — una mejora de **≈21 %** atribuible directamente al cambio de referencia de navegación.
- **Nota de pensamiento sistémico:** este cambio de algoritmo fue posible *gracias* a la decisión de hardware anterior (Decisión 8) — un ejemplo de cómo una decisión de sensado habilitó directamente una mejora de desempeño en el software de navegación. El giroscopio no se retiró del robot: sigue siendo la referencia de rumbo en el Obstacle Challenge, donde los pilares interrumpen la continuidad del muro y el seguimiento de pared no es viable como referencia única.
### Decisión 10 — Evasión de obstáculos: de Pure Pursuit a seguimiento reactivo por distancia
 
- **Contexto/Restricción:** Pure Pursuit requería generar puntos de trayectoria y recalcular constantemente una trayectoria geométrica alrededor de cada obstáculo, lo cual añadía complejidad de cómputo y de diseño.
- **Opciones consideradas:** mantener y refinar Pure Pursuit vs. adoptar un esquema reactivo más simple basado en umbrales de distancia.
- **Decisión y justificación:** se eliminó Pure Pursuit para la evasión de obstáculos y se adoptó un esquema reactivo:
  1. El robot avanza en línea recta.
  2. Al detectar un obstáculo a 50 cm, inicia su seguimiento manteniéndolo centrado en el campo de visión de la HuskyLens.
  3. A 30 cm, comienza a girar para esquivarlo.
  4. El giro continúa hasta perder de vista el obstáculo.
  5. Se ejecuta un protocolo de re-centrado de 10 cuadros respecto al carril antes de continuar recto.
  **Este cambio afecta únicamente al sistema de evasión de obstáculos**; los sensores y el algoritmo de seguimiento de muro (Decisión 9) no se modificaron.
- **Evidencia/Resultado:** validado en las pruebas de evasión de obstáculos del 7 de julio de 2026 (ver Decisión 11).
### Decisión 11 — Validación: pruebas de evasión de obstáculos (7 de julio de 2026)
 
- **Contexto:** validar en pista el esquema reactivo de la Decisión 10.
- **Evidencia/Resultado:** en una sección recta, el robot evadió correctamente un pilar rojo (mantenido a su derecha) y un pilar verde (mantenido a su izquierda). [Ver video de esta prueba](https://youtu.be/mim8iLk7CLE) (video histórico; el video actual en la sección [Obstacle Challenge](#obstacle-challenge) corresponde a una corrida más reciente y completa).
- **Estado actual:** esta prueba corresponde únicamente a un tramo recto de la pista. Continúan las pruebas para validar la evasión de pilares en distintas posiciones y combinaciones de color a lo largo del circuito completo.
### Decisión 12 — Falla de montaje en soportes de sensores laterales: iteración de la solución (26 de julio – 9 de agosto de 2026)

- **Contexto/Restricción:** se detectó que los soportes de MDF de los sensores láser laterales (VL53L0X), al embonar con la base del chasis, quedan ligeramente chuecos con una leve inclinación hacia abajo. Esto provoca que el sensor no lea correctamente la distancia al muro, sino que detecte distancia al suelo.
- **Opciones consideradas:** ajustar/calzar manualmente los soportes de MDF existentes vs. diseñar un soporte a la medida en CAD e imprimirlo en 3D con PLA.
- **Plan inicial (28 de julio de 2026):** el equipo concluyó que la mejor solución era diseñar soportes nuevos en digital e imprimirlos en 3D con PLA, con un ángulo de montaje corregido, para sustituir las piezas de MDF actuales.
- **Iteración 1 — solución realmente implementada:** en la práctica, el equipo decidió **no fabricar soportes nuevos con otro ángulo**. En su lugar, se reutilizaron los mismos soportes de MDF ya existentes, reubicándolos pegados en la parte inferior del segundo piso del chasis, justo por encima de su posición original. Esto elevó a los sensores hasta aproximadamente **8 cm** sobre el suelo.
- **Nuevo hallazgo (9 de agosto de 2026):** dado que los muros de la pista miden **10 cm** de altura, esta nueva posición (8 cm) deja poco margen respecto al borde superior del muro, generando incertidumbre sobre qué tan confiable es la lectura de distancia a esa altura.
- **Iteración 2 — solución definitiva (desde el 9 de agosto de 2026):** el equipo diseñará soportes que conserven el mismo ángulo y simetría que los soportes actuales, pero de **mayor longitud**, y los regresará a la **posición de montaje original** (no a la ubicación temporal bajo el segundo piso). Así, los sensores quedarán más elevados que en su posición original, sin depender de la reubicación provisional.
- **Iteración 3 — pieza final impresa en 3D:** se diseñó e imprimió un nuevo soporte (`SoporteLaser.STL`, ver [Piezas de Diseño Mecánico](#piezas-cad)) que eleva al sensor casi 4 cm por encima del soporte de MDF original, corrigiendo la inclinación. El equipo confirma que esto resolvió las falsas lecturas y dio un comportamiento más constante.
- **Estado actual:** ✅ **Resuelto.**
### Decisión 13 — Corrección de deriva: orificio de eje mal dimensionado en soporte impreso del motor (3 de agosto de 2026)

- **Contexto/Restricción:** al medir el desempeño del robot en tramos rectos (~3 metros), se detectó una **deriva** (desviación angular) excesiva: en lugar de avanzar en línea recta, el robot se abría formando una trayectoria en forma de triángulo respecto a la línea ideal. La desviación medida era de aproximadamente **45°**.
- **Diagnóstico:** al probar el robot suspendido en el aire (sin contacto con el suelo), se observó que una de las llantas (lado izquierdo, visto desde atrás del robot) no giraba. La causa: el orificio del eje en la pieza impresa en 3D que sostiene el motor (soporte naranja, visible en la foto trasera del robot) era ligeramente más pequeño que la medida real del eje (*axle*) de Lego, generando un ajuste a presión excesivo. Esto provocaba que esa rueda solo girara cuando había contacto y fricción con el suelo, avanzando más lento que el lado contrario y generando la deriva.

<div align="center">
Vista trasera del robot, soporte impreso del motor
<br><sub>Vista trasera — soporte impreso del motor (pieza naranja) donde se detectó el orificio del eje mal dimensionado.</sub>
</div>

- **Decisión y acción correctiva:** se agrandó el orificio del soporte impreso con una broca de taladro, permitiendo que el eje gire libremente en cualquier circunstancia, tanto suspendido en el aire como en contacto con la pista.
- **Evidencia/Resultado:** la rueda ahora gira correctamente en ambas condiciones, tanto suspendida en el aire como sobre la pista. La deriva del robot es **mucho menor** que antes de la corrección, y el tiempo de recorrido en el Open Challenge mejoró de forma notoria en la misma sesión — resultado consistente con una trayectoria más recta y con menos correcciones necesarias durante el recorrido.
- **Estado:** mejora confirmada; el equipo continúa dando seguimiento a la deriva restante para reducirla aún más.
### Decisión 14 — Recalibración de umbrales de evasión y validación en ¾ de vuelta (9 de agosto de 2026)

- **Contexto:** el esquema reactivo de evasión de obstáculos (Decisión 10) solo se había validado en un tramo recto de la pista (Decisión 11, 7 de julio de 2026), usando umbrales fijos de 50 cm (inicio de seguimiento) y 30 cm (inicio del giro de evasión).
- **Decisión y cambio:** tras pruebas iterativas, se recalibraron los umbrales de distancia:
  - **Seguimiento del obstáculo:** ahora entre **60 cm y 30 cm** (antes: umbral único de 50 cm).
  - **Inicio de la secuencia de evasión:** ahora entre **25 cm y 20 cm** (antes: umbral único de 30 cm), con una **desviación progresiva** conforme el robot se acerca al obstáculo, en lugar de un giro más abrupto a partir de un solo umbral.
  - **Regla de color (sin cambio):** pilar verde → evasión por la izquierda; pilar rojo → evasión por la derecha.
- **Evidencia/Resultado:** se validó el esquema recalibrado en una prueba que cubre **≈3/4 de una vuelta completa** de la pista — una cobertura mucho mayor que la prueba anterior, limitada a un tramo recto (Decisión 11) — detectando y evadiendo obstáculos según su color y distancia de forma consistente. [Ver video de esta prueba](https://youtube.com/shorts/EIXM7CX9vMc?feature=share) (video histórico; el video actual en la sección [Obstacle Challenge](#obstacle-challenge) corresponde a una corrida más reciente y completa).
- **Estado:** umbrales vigentes del sistema de evasión de obstáculos.
### Decisión 15 — Descontinuación del sensor infrarrojo de esquina (10 de agosto de 2026)

- **Contexto:** el sensor infrarrojo MH Sensor Series, agregado el 28 de junio de 2026 para leer las líneas de esquina y complementar los sensores laterales VL53L0X (Decisión 7), estuvo activo hasta el 9 de agosto de 2026.
- **Decisión:** se dejó de utilizar a partir del **10 de agosto de 2026**. Se retiró del BOM y de las especificaciones actuales del vehículo (tabla "Potencia y Sensores").
- **Nota:** las entradas de la Bitácora y el video de Open Challenge que documentan pruebas anteriores a esta fecha (Decisión 7, 28 de junio de 2026) se conservan sin cambios, ya que describen correctamente el estado del robot en ese momento.
### Decisión 16 — Validación: corrida completa del Obstacle Challenge (23 de agosto de 2026)

- **Contexto:** hasta esta fecha, el Obstacle Challenge solo se había validado por tramos: un segmento recto (Decisión 11) y ≈3/4 de vuelta (Decisión 14). Faltaba comprobar que la máquina de estados sostuviera el comportamiento a lo largo de una corrida larga, donde se acumulan esquinas, esquives y deriva del giroscopio.
- **Evidencia/Resultado:** el **23 de agosto de 2026** el robot completó una corrida de **2 min 18 s** encadenando de forma autónoma el ciclo completo: seguimiento de rumbo recto, detección y esquive de pilares según color, y detección y giro de esquinas — sin intervención manual y sin desplazar señales. [Ver video](https://youtu.be/mVZCY8PyXOI).
- **Qué valida esta prueba:** que las tres piezas del sistema (percepción por color, seguimiento de rumbo por giroscopio y detección de esquina por ToF en modo de largo alcance) conviven sin interferirse a lo largo de una corrida larga, y que las salvaguardas de tiempo descritas en el punto 10 de [Arquitectura de Software](#ingenieria-defensiva) mantienen al robot fuera de estados bloqueados.
- **Estado:** comportamiento vigente del Obstacle Challenge.
[⬆ Volver al índice](#indicleto)
 
---

## 5. Reproducibilidad y Estructura del Repositorio

> [!NOTE]
> Esta sección existe para que **otro equipo pueda tomar este repositorio y reconstruir el robot** solo con lo que hay aquí: qué archivo es cada cosa, cómo se compila, y cómo se gestiona el historial de cambios.

### Estructura del repositorio

```
├── README.md                          # Este documento
├── abierto.ino                        # Código del Open Challenge (ver Arquitectura de Software, 3.1)
├── obstaculos.ino                     # Código del Obstacle Challenge (ver Arquitectura de Software, 3.2)
├── cad/                                # Piezas de diseño mecánico en .STL (ver Movilidad y Diseño Mecánico)
│   ├── S25_chasis_rev18.STL
│   ├── S25_Plataforma_Soporte_Rev_8.STL
│   ├── S25_Soporte_de_motor_y_transmision_Rev_4B.STL
│   ├── S25_Mangueta_Rev_2.STL
│   ├── R26_EnlaceDireccion_Rev7.STL
│   └── SoporteLaser.STL
├── schemes/                            # Fotos de componentes (BOM) y diagramas de cableado
├── v-photos/                            # Fotos del vehículo (6 vistas + fotos de pruebas)
└── t-photos/                            # Foto del equipo
```

### Cómo compilar y cargar cada programa

1. Instalar el **Arduino IDE**.
2. Instalar las librerías que usa cada programa (Administrador de Librerías → buscar por nombre):
   - **Ambos programas:** `Wire` (incluida con el IDE), `MPU6050_light`.
   - **`abierto.ino`** (Open Challenge): `Adafruit_VL53L0X`, `Servo` (incluida con el IDE).
   - **`obstaculos.ino`** (Obstacle Challenge): `Adafruit_VL53L0X`, `SCServo` (librería de Waveshare para el ST3215), `HUSKYLENS` (librería oficial de DFRobot).
3. Abrir el archivo correspondiente al reto (`abierto.ino` u `obstaculos.ino`).
4. Seleccionar placa **Arduino Mega 2560** y el puerto correspondiente.
5. Verificar que el HuskyLens esté configurado en modo **I2C** (solo aplica para `obstaculos.ino`) y que el algoritmo de reconocimiento de color tenga aprendidos los colores rojo y verde antes de correr el programa.
6. Cargar el programa. En `obstaculos.ino`, el robot espera a que se presione el botón de arranque (pin 23) antes de empezar a moverse.

### Convención de commits y versionado

- **Mensajes de commit descriptivos**, en la línea de: `feat: agregar recalibración de umbrales de esquive`, `fix: corregir orificio de eje en soporte de motor`, `docs: actualizar README con arquitectura de potencia`.
- **Historial de commits conforme al reglamento**: al menos 3 commits, el primero con al menos 1/5 del código final y con al menos dos meses de anticipación a la competencia, el segundo con al menos un mes de anticipación, y el tercero (el que se evalúa) con al menos dos semanas de anticipación.
- **Etiquetas de versión (tags)** en los hitos importantes de la Bitácora, por ejemplo: `v1.0` (Regional Mexicali), `v1.1` (post-regional: VL53L0X laterales + wall-following), `v1.2` (algoritmo de evasión reactivo), `v1.3` (servo ST3215-HS + soportes rediseñados).

### Trazabilidad entre código, pruebas y documentación

Cada cambio de fondo documentado en la [Bitácora](#bitacora-decisiones) tiene su evidencia correspondiente en otra parte del repositorio, para que se pueda verificar en lugar de solo tomarlo por escrito:

| Tipo de cambio | Dónde vive el código/evidencia |
|---|---|
| Cambios de hardware (sensores, chasis, servos) | [Piezas de Diseño Mecánico](#piezas-cad) (`/cad`) y [BOM](#bom) |
| Cambios de algoritmo | `abierto.ino` / `obstaculos.ino`, explicados en [Arquitectura de Software](#arquitectura-software) |
| Validación en pista | [Videos de la Competencia](#videos-de-la-competencia) |

[⬆ Volver al índice](#indicleto)
 
---
 
## Videos de la Competencia

Conforme al reglamento oficial WRO 2026 – Future Engineers, cada equipo debe publicar un video en YouTube (público o accesible mediante enlace) que documente el manejo autónomo del vehículo para cada reto, con una duración mínima de 30 segundos por video.
 
| Reto | Estado | Enlace | Duración del recorrido |
|---|---|---|---|
| **Open Challenge** (Vuelta Abierta) | ✅ Publicado | [Ver en YouTube](https://youtu.be/jBpTh44YIUg) | 75 s |
| **Obstacle Challenge** (Vuelta con Obstáculos) | ✅ Publicado | [Ver en YouTube](https://youtu.be/mVZCY8PyXOI) | 2 min 18 s |
 
### Open Challenge
 
<div align="center">
<a href="https://youtu.be/jBpTh44YIUg">Video Open Challenge</a>
</div>
El video corresponde a la prueba de la ronda de vuelta abierta realizada el **28 de junio de 2026**. En la corrida documentada, el robot:
 
- Ejecuta de forma autónoma **3 vueltas consecutivas** sobre la pista.
- Se estaciona en el **cuadrante de inicio** del recorrido, sin intervención manual.
- Completa la totalidad del reto en **75 segundos**.
**Sistemas involucrados durante la corrida:** seguimiento de muro mediante sensores VL53L0X laterales para la toma de curvas, sensor infrarrojo MH Sensor Series en el extremo trasero inferior para lectura de líneas de esquina, y HuskyLens + Arduino Mega como unidad de control principal.
 
### Obstacle Challenge
 
<div align="center">
<a href="https://youtu.be/mVZCY8PyXOI">Video Obstacle Challenge</a>
</div>
El video corresponde a una corrida completa de evasión de obstáculos realizada el **23 de agosto de 2026**, con una duración de **2 min 18 s** (ver Bitácora, **Decisión 16**). El robot detecta y evade los obstáculos según su color y distancia:
 
- **Pilar verde:** se evade por la **izquierda**.
- **Pilar rojo:** se evade por la **derecha**.

**Sistemas involucrados durante la corrida:** detección de color mediante la cámara HuskyLens; seguimiento del obstáculo manteniéndolo centrado en cámara entre **60 y 30 cm** de distancia; inicio de la secuencia de evasión entre **25 y 20 cm**, con desviación progresiva conforme el robot se acerca; detección y giro de esquinas; y protocolo de re-centrado de 10 cuadros al perder de vista el obstáculo.

> [!NOTE]
> Los videos anteriores de Obstacle Challenge (tramo recto del 7 de julio, ≈3/4 de vuelta del 9 de agosto) se conservan en la Bitácora como evidencia histórica de la evolución del sistema — ver Decisiones 11 y 14.
 
[⬆ Volver al índice](#indicleto)
 
---

## BOM (Bill of Materials)
 
| Componente | Requerimiento de energía | Imagen | Precio |
|---|---|---|---|
| Arduino Mega 2560 | 0.25-0.5W |  | ≈ 24.46 Dlls |
| Motor DC con Encoder: GA37-520 300RPM | 5.55-16.65W |  | ≈ 22.12 Dlls |
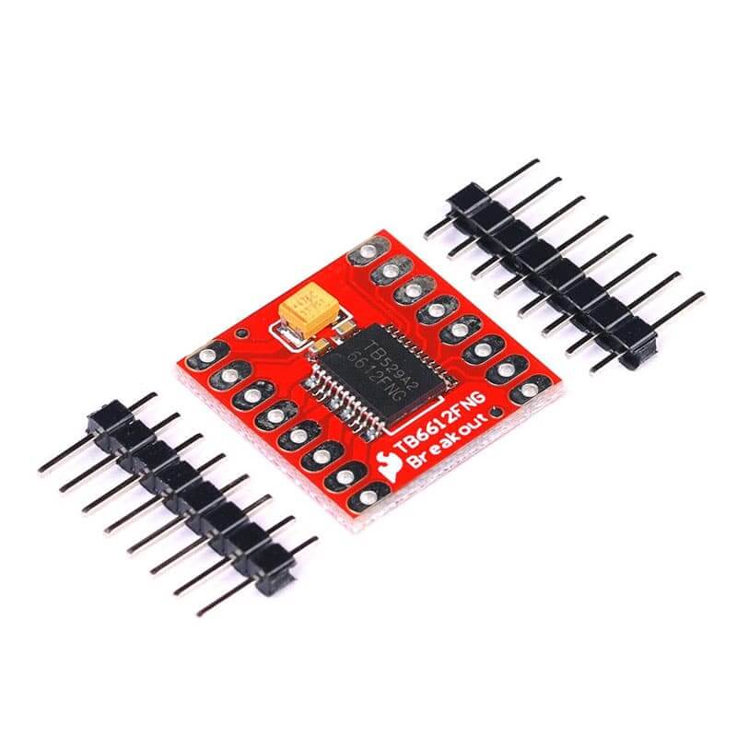
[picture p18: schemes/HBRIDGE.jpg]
| Puente H TB6612FNG | 0.025W |  | ≈ 4.35 Dlls |
| Servo Motor: MG90S (Open Challenge) | 0.5-2.5W |  | ≈ 4.08 Dlls |
| Servo de bus serial: Waveshare ST3215-HS (Obstacle Challenge) | 0.75-6.75W (0.1-0.9A a 7.5V) |  | ≈ 18.00 Dlls |
| Sensor Ultrasonico: HC-SR04P x1 (frontal) | 0.075W |  | ≈ 0.90 Dlls |
| Sensor Láser ToF: VL53L0X x2 (laterales) | ≈ 0.10W |  | ≈ 9.00 Dlls |
| Acelerometro/Giroscopio: GY-9250 | 0.033W |  | ≈ 9.24 Dlls |
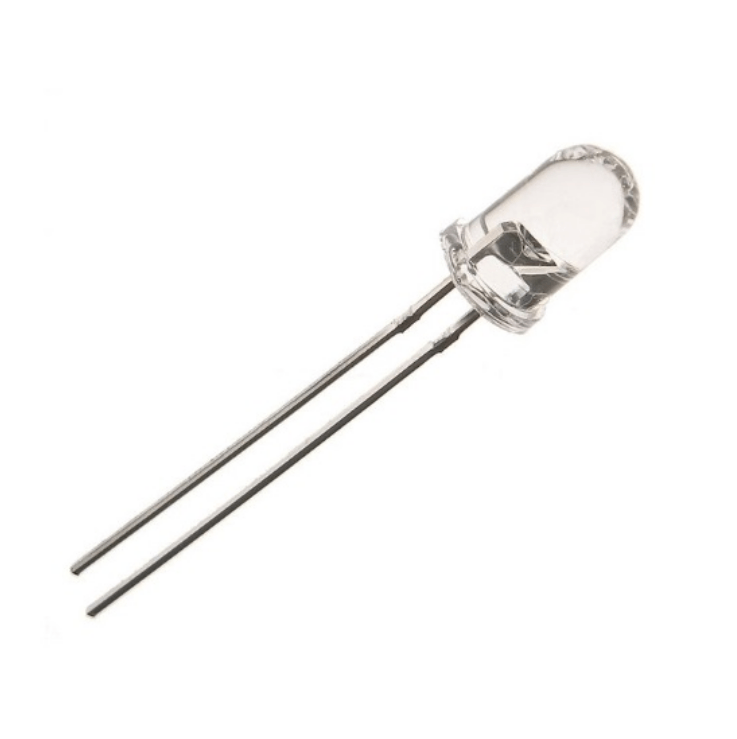
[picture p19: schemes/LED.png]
| LED x4 | 0.264W |  | ≈ 0.44 Dlls |
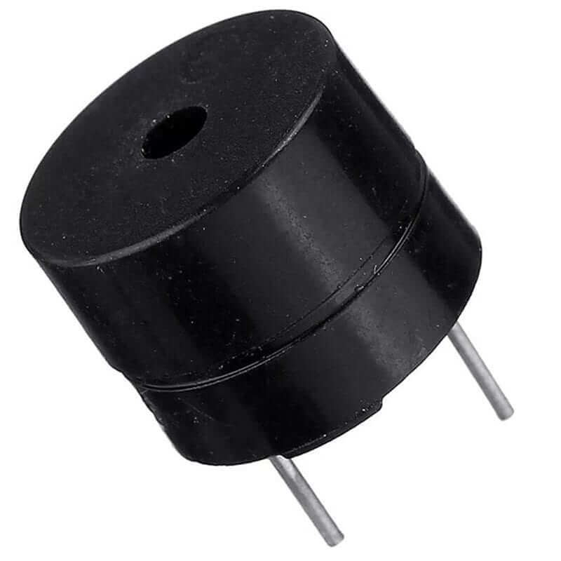
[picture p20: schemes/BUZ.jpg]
| Buzzer | N/A |  | ≈ 0.27 Dlls |
| SEN0336 HuskyLens PRO OV5640 | 3.3~5.0V |  | ≈ 40.65 Dlls |
| **Total** | | | **≈ 133.51 Dlls** |

> [!NOTE]
> El sensor infrarrojo (MH Sensor Series) se retiró de este BOM porque se dejó de usar a partir del **10 de agosto de 2026** — ver Bitácora, **Decisión 15**.

> [!NOTE]
> El robot usa un servomotor distinto en cada reto: **MG90S** en el Open Challenge y **ST3215-HS** en el Obstacle Challenge — ver [Arquitectura de Software](#arquitectura-software) y [Arquitectura de Potencia](#arquitectura-potencia).
 
[⬆ Volver al índice](#indicleto)

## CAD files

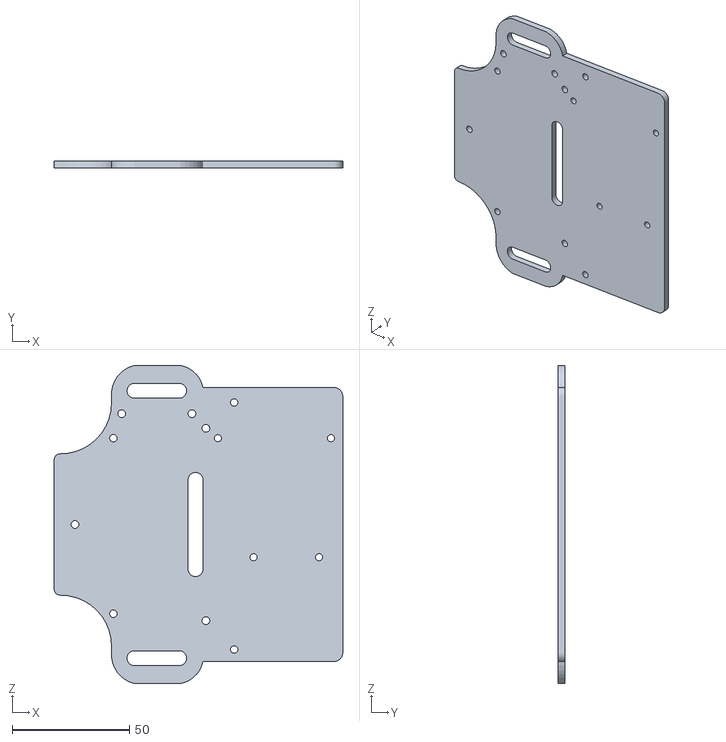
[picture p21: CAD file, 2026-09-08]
cad/R26_piso_1_rev2.STL
123.2 x 3.12 x 135.7

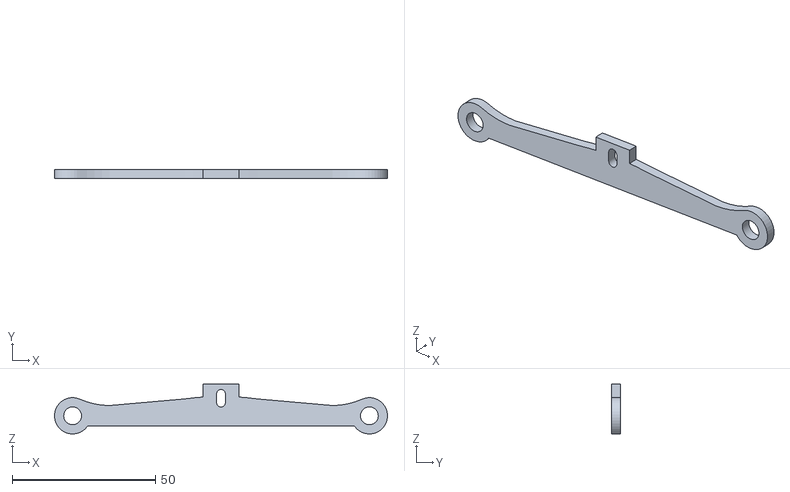
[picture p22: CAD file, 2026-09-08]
cad/R26_EnlaceDireccion_Rev7.STL
116.4 x 3.12 x 17.4

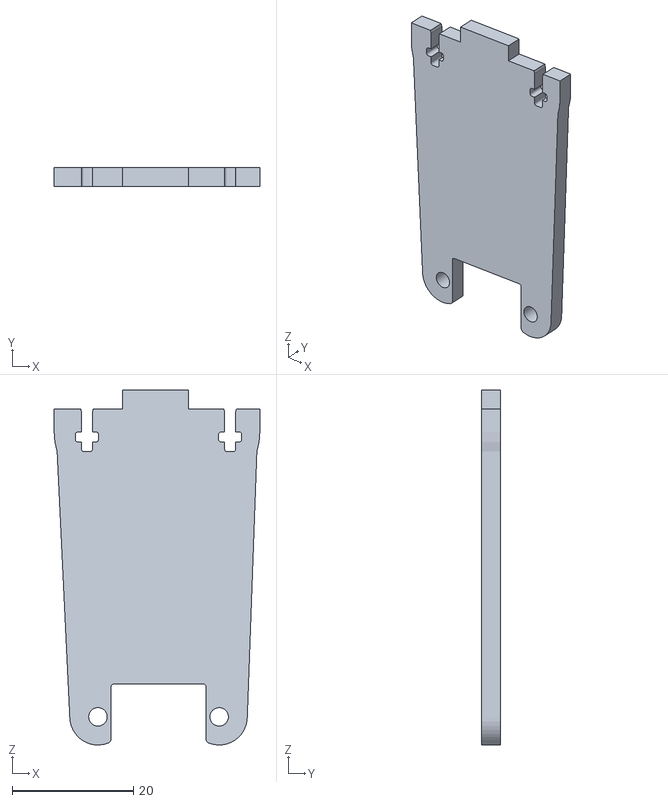
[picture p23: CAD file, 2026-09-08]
cad/SoporteLaser.STL
33.9 x 3.12 x 58.6

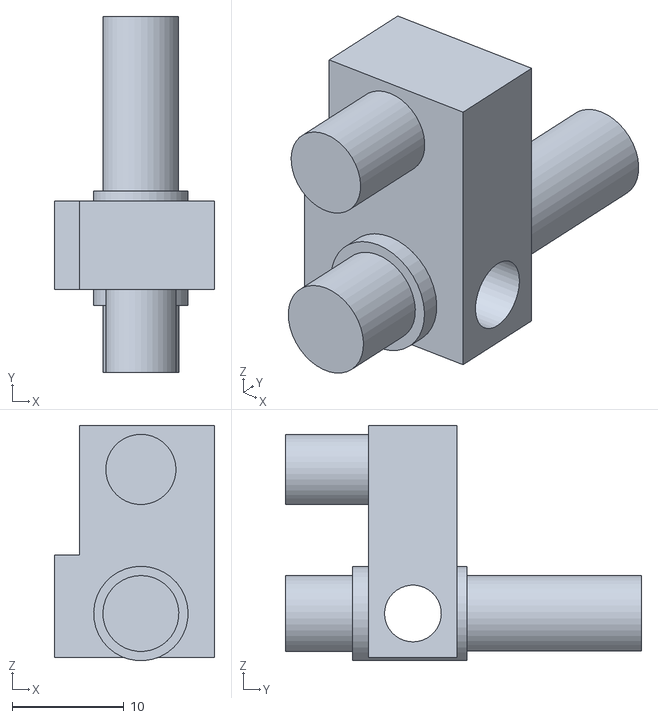
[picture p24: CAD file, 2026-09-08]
cad/S25_Mangueta_Rev_2.STL
14.4 x 31.9 x 21.0

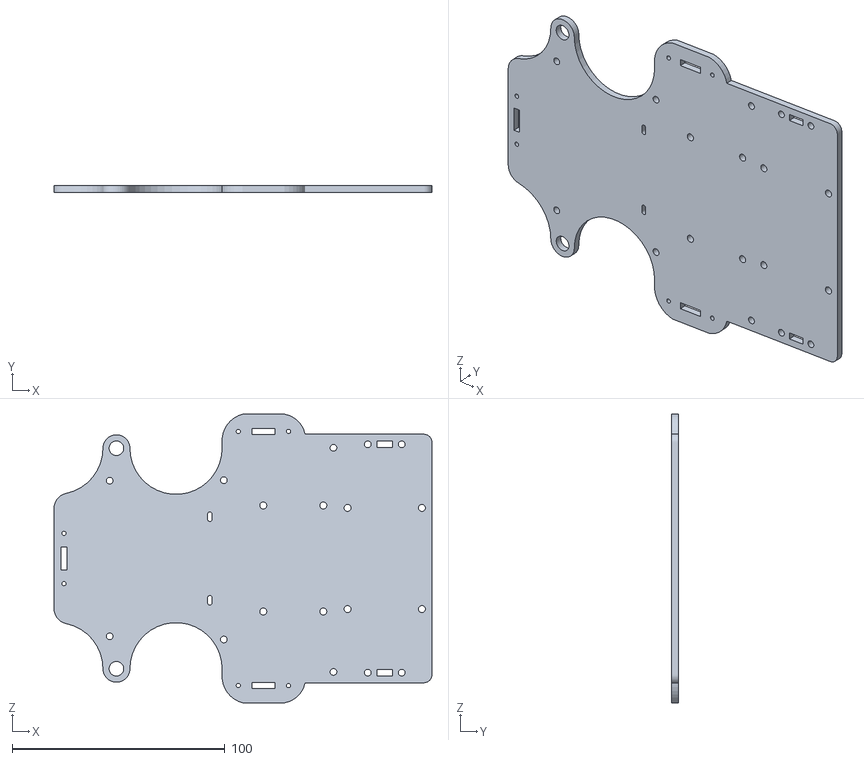
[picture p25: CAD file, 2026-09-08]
cad/S25_chasis_rev18.STL
177.8 x 3.12 x 135.7

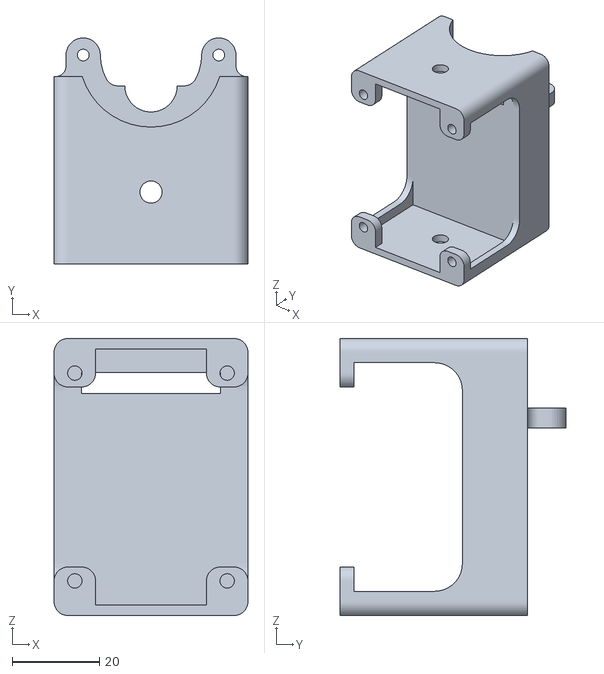
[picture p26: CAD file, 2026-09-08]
cad/S25_Soporte_de_motor_y_transmision_Rev_4B.STL
44.5 x 51.8 x 63.5

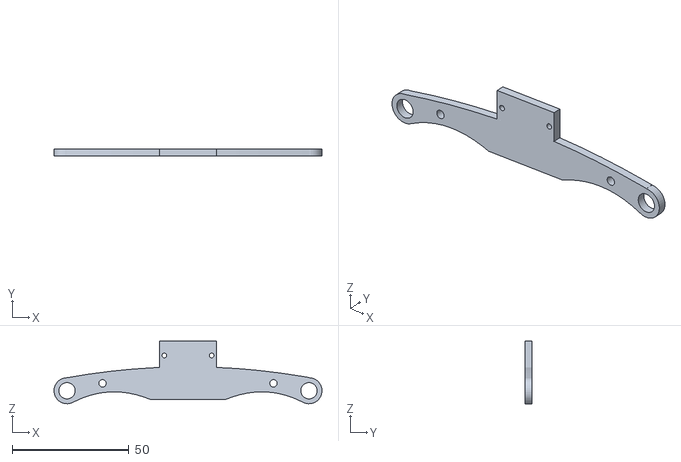
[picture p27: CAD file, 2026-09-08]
cad/S25_Soporte_Servo_Rev_8.STL
114.9 x 3.12 x 26.8

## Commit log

2026-07-16 Mejora en el orden y estructura
2026-08-18 Explicacion en funcionamiento de algoritmo
2026-08-25 arquitectura y potencia de sensores
2026-09-08 Rename S25 Soporte de motor y transmision Rev 4B.STL to S25_Soporte_de_motor_y_transmision_Rev_4B.STL
    [S25_Soporte_de_motor_y_transmision_Rev_4B.STL]
2026-09-08 Rename S25 Plataforma Soporte Rev 8.STL to S25_Plataforma_Soporte_Rev_8.STL
    [S25_Plataforma_Soporte_Rev_8.STL]
2026-09-08 Rename S25 chasis rev18.STL to S25_chasis_rev18.STL
    [S25_chasis_rev18.STL]
2026-09-08 Rename S25 Mangueta Rev 2.STL to S25_Mangueta_Rev_2.STL
    [S25_Mangueta_Rev_2.STL]
2026-09-08 Rename R26 piso 1 rev2 .STL to R26_piso_1_rev2.STL
    [R26_piso_1_rev2.STL]
